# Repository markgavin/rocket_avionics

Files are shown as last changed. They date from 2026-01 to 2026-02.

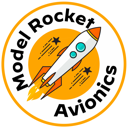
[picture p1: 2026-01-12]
artwork/ModelRocketAvionic128pt.png

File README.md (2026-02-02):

# Rocket Avionics Flight Computer

A complete model rocket avionics system with real-time LoRa telemetry, dual parachute deployment, GPS tracking, and multi-rocket support. Includes flight computer, ground gateway, and desktop/iOS companion apps.

## Overview

The Rocket Avionics system provides comprehensive flight monitoring and recovery capabilities for model and high-power rockets. Real-time telemetry is transmitted via LoRa radio to a ground station, with GPS coordinates enabling rocket recovery after landing.

### Key Features

- **Multi-rocket support** - Track up to 16 rockets simultaneously (IDs 0-15)
- **10 Hz telemetry** via LoRa radio (915 MHz)
- **GPS tracking** with position saved for offline recovery
- **Dual parachute deployment** - Drogue at apogee, main at configurable altitude
- **9-DoF IMU** - Accelerometer, gyroscope, and magnetometer
- **Barometric altitude** using BMP390 precision sensor
- **WiFi connectivity** - Connect apps directly to gateway over WiFi
- **OTA updates** - Update Heltec gateway firmware over WiFi
- **mDNS discovery** - Find gateway at `RocketGateway.local`
- **Cross-platform apps** for macOS, Windows, and iOS
- **Rocket recovery navigation** - iOS app guides you to landed rocket

## System Components

### 1a. Flight Computer - RP2040 (`/firmware_flight/`)
RP2040-based flight computer with Feather ecosystem.

- **Feather RP2040 + RFM95** LoRa radio (915 MHz)
- **BMP390** barometric altitude sensor
- **LSM6DSOX + LIS3MDL** 9-DoF IMU
- **GPS module** for position tracking
- **OLED display** with button navigation
- **Dual pyro channels** with continuity detection
- **~$125 total cost**

### 1b. Flight Computer - Heltec (Lower Cost) (`/firmware_flight_heltec/`)
ESP32-S3 based flight computer with built-in GPS and display.

- **Heltec Wireless Tracker** (ESP32-S3 + SX1262 + GPS + Display)
- **BMP390** barometric altitude (external I2C)
- **LSM6DSOX + LIS3MDL** 9-DoF IMU (external I2C)
- **Built-in GPS** and TFT display
- **Dual pyro channels** with continuity detection
- **~$81 total cost (35% savings)**

### 2. Ground Gateway - Heltec (Recommended) (`/firmware_gateway_heltec/`)
ESP32-S3 based gateway with built-in WiFi, GPS, and display.

- **Heltec Wireless Tracker** (ESP32-S3 + SX1262 + GPS)
- **WiFi AP/Station mode** - Create hotspot or join existing network
- **mDNS** - Discover at `RocketGateway.local`
- **OTA updates** - Flash new firmware over WiFi
- **Built-in display** - Shows rocket status, GPS, packet count
- **TCP server** on port 5000 for app connections

### 3. Ground Gateway - RP2040 (`/firmware_gateway/`)
Alternative gateway using RP2040 with optional WiFi.

- **Feather RP2040 + RFM95** LoRa radio
- **USB serial** output for desktop connection
- **Optional AirLift** WiFi FeatherWing

### 4. Desktop Application (`/desktop_app/`)
Xojo application for macOS and Windows.

- Real-time altitude/velocity charts
- Multi-rocket tracking with rocket list
- Rename rockets with custom names
- Flight data download from flash storage
- Gateway status and configuration
- Flight history database
- Data export (CSV)

### 5. iOS Application (`/ios_app/`)
Xojo mobile app for iPhone.

- Live telemetry display
- **Rocket recovery navigation** - Compass and distance to landed rocket
- Uses iPhone GPS to guide you to rocket location
- Works offline with cached rocket coordinates
- Multi-rocket support with individual recovery

## Hardware

### Flight Computer (RP2040 - Full Featured)
| Component | Description |
|---|---|
| Adafruit Feather RP2040 + RFM95 | MCU with 915 MHz LoRa radio |
| Adafruit BMP390 | Barometric pressure/altitude |
| Adafruit LSM6DSOX + LIS3MDL | 9-DoF IMU FeatherWing |
| Adafruit FeatherWing OLED 128x64 | Status display with buttons |
| GPS Module | UART GPS for position tracking |

### Flight Computer (Heltec - Lower Cost)
| Component | Description |
|---|---|
| Heltec Wireless Tracker | ESP32-S3 + SX1262 + GPS + Display |
| Adafruit BMP390 | Barometric pressure (I2C) |
| Adafruit LSM6DSOX + LIS3MDL | 9-DoF IMU (I2C) |

### Ground Gateway (Heltec - Recommended)
| Component | Description |
|---|---|
| Heltec Wireless Tracker | ESP32-S3 + SX1262 LoRa + GPS + Display |

### Ground Gateway (RP2040 - Alternative)
| Component | Description |
|---|---|
| Adafruit Feather RP2040 + RFM95 | MCU with 915 MHz LoRa radio |
| Adafruit AirLift FeatherWing | Optional WiFi (ESP32) |

## Quick Start

### Flight Computer
```bash
cd firmware_flight
mkdir -p build && cd build
cmake .. && make -j4
picotool load rocket_avionics_flight.uf2 -f
```

### Heltec Gateway
```bash
cd firmware_gateway_heltec
./increment_build.sh
# Use Arduino IDE or arduino-cli to compile and upload
```

### OTA Update (Heltec Gateway)
```bash
python3 ~/Library/Arduino15/packages/Heltec-esp32/hardware/esp32/3.0.3/tools/espota.py \
  -i RocketGateway.local -p 3232 -f firmware_gateway_heltec.ino.bin
```

### Connect to Gateway
```bash
# Via mDNS hostname
nc RocketGateway.local 5000

# Query gateway info
echo '{"cmd":"gw_info"}' | nc RocketGateway.local 5000
```

## Flight Computer Display

The OLED display has two buttons for navigation:

| Button | Action |
|---|---|
| **A** | Cycle through screens: Live → Sensors → Pyro → Storage → Rocket ID → About |
| **B** | On Rocket ID screen: Change ID (0-15). On other screens: Return to Live |

## Multi-Rocket Support

Each flight computer has a unique rocket ID (0-15):

1. Navigate to **Rocket ID** screen (Button A)
2. Press **Button B** to cycle through IDs
3. ID is saved to flash and persists across reboots
4. All telemetry packets include the rocket ID
5. Gateway and apps track all rockets independently

## Flight States

| State | Description | Trigger |
|---|---|---|
| IDLE | On pad, pre-flight | Power on |
| ARMED | Ready for launch | ARM command |
| BOOST | Motor burning | Altitude >10m or velocity >10m/s |
| COAST | Coasting to apogee | Acceleration drops |
| APOGEE | Peak altitude | Velocity crosses zero (fires drogue) |
| DROGUE | Descending on drogue | Drogue deployed |
| MAIN | Main chute altitude | Below configured altitude (fires main) |
| LANDED | On ground | Stationary for 5 seconds |

## Pyro Channels

| Channel | Purpose | Fire Condition |
|---|---|---|
| Pyro 1 | Drogue parachute | At apogee (velocity = 0) |
| Pyro 2 | Main parachute | Below main deploy altitude |

**Safety:** Arm switch must be closed to enable pyro firing.

## Directory Structure

```
rocket_avionics/
├── firmware_flight/          # Flight computer (RP2040, C)
├── firmware_flight_heltec/   # Flight computer (Heltec, Arduino)
├── firmware_gateway/         # RP2040 gateway (C)
├── firmware_gateway_heltec/  # Heltec gateway (Arduino)
├── desktop_app/              # Desktop app (Xojo)
├── ios_app/                  # iOS app (Xojo)
├── hardware/                 # PCB designs
├── docs/                     # Documentation
└── tools/                    # Utility scripts
```

## Documentation

- `CLAUDE.md` - Project overview and coding conventions
- `firmware_flight/CLAUDE.md` - RP2040 flight computer details
- `firmware_flight_heltec/CLAUDE.md` - Heltec flight computer details
- `firmware_gateway_heltec/CLAUDE.md` - Heltec gateway (OTA, mDNS, GPS)
- `desktop_app/CLAUDE.md` - Desktop application
- `ios_app/CLAUDE.md` - iOS app (recovery, multi-rocket)
- `docs/flight_computer_parts_list.md` - RP2040 flight computer BOM
- `docs/heltec_flight_computer_parts_list.md` - Heltec flight computer BOM
- `docs/gateway_parts_list.md` - Gateway options BOM

## License

Copyright (c) 2025-2026 by Mark Gavin. All Rights Reserved.

Proprietary software - not for distribution.

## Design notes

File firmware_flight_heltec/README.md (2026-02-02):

# Heltec Flight Computer

Rocket flight computer firmware for Heltec Wireless Tracker with external BMP390 and IMU sensors.

## Features

- Real-time telemetry at 10Hz via LoRa
- GPS tracking with built-in module
- 9-DoF IMU (accelerometer, gyroscope, magnetometer)
- Barometric altitude measurement
- Dual parachute deployment (drogue + main)
- View-only TFT display
- ~47% cost savings vs RP2040 version

## Hardware Required

| Component | Description | Est. Price |
|---|---|---|
| Heltec Wireless Tracker | ESP32-S3 + SX1262 + GPS + Display | $27 |
| Adafruit BMP390 | Barometric sensor (STEMMA QT) | $12.50 |
| Adafruit LSM6DSOX + LIS3MDL | 9-DoF IMU FeatherWing | $19.95 |
| LiPo Battery 3.7V | 500-1000mAh | $8 |
| **Total** | | **~$67** |

Plus pyro channel components (~$7).

## Wiring

### I2C Sensors

Solder wires from Heltec edge connector to sensors:

| Heltec GPIO | Connect To |
|---|---|
| GPIO 5 | SDA (BMP390 + IMU) |
| GPIO 6 | SCL (BMP390 + IMU) |
| 3.3V | VIN (sensors) |
| GND | GND (sensors) |

### Pyro Channels

| Heltec GPIO | Connect To |
|---|---|
| GPIO 7 | Pyro 1 MOSFET gate (drogue) |
| GPIO 45 | Pyro 2 MOSFET gate (main) |
| GPIO 2 | Pyro 1 continuity divider |
| GPIO 4 | Pyro 2 continuity divider |
| GPIO 46 | Arm switch (to GND when armed) |

## Arduino IDE Setup

1. **Add Heltec board URL** to File → Preferences → Additional Board Manager URLs:
   ```
   https://github.com/Heltec-Aaron-Lee/WiFi_Kit_series/releases/download/0.0.9/package_heltec_esp32_index.json
   ```

2. **Install board**: Tools → Board → Board Manager → Search "Heltec ESP32" → Install

3. **Install libraries** via Library Manager:
   - RadioLib
   - TinyGPSPlus
   - Adafruit GFX Library
   - Adafruit ST7735 and ST7789 Library

4. **Select board**: Tools → Board → Heltec ESP32 → Heltec Wireless Tracker

5. **Upload speed**: 921600

## Building and Flashing

```bash
# Increment build number
./increment_build.sh

# Compile and upload via Arduino IDE
# Or use arduino-cli:
arduino-cli compile --fqbn "Heltec-esp32:esp32:heltec_wireless_tracker" .
arduino-cli upload --fqbn "Heltec-esp32:esp32:heltec_wireless_tracker" -p /dev/cu.usbserial-* .
```

## Flight Procedure

### Pre-Flight

1. Power on flight computer
2. Verify display shows "IDLE" state
3. Wait for GPS lock (green "FIX" on display)
4. Verify pyro continuity (P1:OK, P2:OK)
5. Close arm switch
6. Verify ARM:YES on display
7. Send ARM command from ground station

### Launch

1. Flight computer automatically detects launch (>2g accel or >10m altitude)
2. Real-time telemetry transmitted to gateway
3. Apogee detected → drogue deployed
4. Main altitude reached → main deployed
5. Landing detected → beacon mode

### Post-Flight

1. Open arm switch first!
2. Download flight data via LoRa
3. Power off

## Display Screens

The display shows (no buttons, view-only):

- **Line 1**: Flight state + Rocket ID
- **Line 2**: Altitude + Velocity
- **Line 3**: Max altitude + Acceleration
- **Line 4**: GPS status
- **Line 5**: Pyro continuity + Arm status
- **Line 6**: TX count + Temperature

## Troubleshooting

**Sensors not found**
- Check solder connections on GPIO 5 and 6
- Verify 3.3V power to sensors
- Run I2C scanner sketch to find addresses

**No GPS fix**
- Go outdoors with clear sky view
- Wait 1-2 minutes for cold start
- Built-in antenna is weak but works outdoors

**LoRa not working**
- Check antenna is connected
- Verify gateway is running
- Check sync word matches (0x14)

## License

Copyright (c) 2025-2026 by Mark Gavin. All Rights Reserved.

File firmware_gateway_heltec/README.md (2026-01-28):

# Heltec Gateway Firmware (ESP32-S3)

## Overview

Ground station gateway firmware for Heltec Wireless Tracker. Bridges LoRa telemetry from flight computer to WiFi TCP clients with built-in GPS for ground station location.

## Hardware

- **Board:** Heltec Wireless Tracker (ESP32-S3 + SX1262 LoRa + GPS)
- **LoRa:** SX1262 915MHz with onboard PCB antenna
- **Display:** Built-in 0.96" TFT (ST7735, 160x80 pixels, color)
- **GPS:** Built-in UC6580 GPS module with ceramic chip antenna
- **WiFi:** Built-in ESP32-S3 WiFi

## Antennas

The Wireless Tracker has **built-in antennas** - no external antennas required:

| Antenna | Type | Notes |
|---|---|---|
| **LoRa** | Onboard spring/wire antenna | Ready to use |
| **GPS** | Ceramic chip antenna on PCB | Needs clear sky view for fix |

For extended LoRa range, you can optionally add an external 915MHz antenna via the U.FL connector (if present on your board version).

## Arduino IDE Setup

### 1. Install Heltec Board Support

Add this URL to **File > Preferences > Additional Board Manager URLs**:
```
https://resource.heltec.cn/download/package_heltec_esp32_index.json
```

Install **Heltec ESP32 Series Dev-boards** from Board Manager.

### 2. Install Required Libraries

Go to **Tools > Manage Libraries** and install:
- **RadioLib** by Jan Gromes
- **TinyGPSPlus** by Mikal Hart
- **Adafruit GFX Library** by Adafruit
- **Adafruit ST7735 and ST7789 Library** by Adafruit

### 3. Select Board and Port

- **Board**: Tools → Board → Heltec Wireless Tracker
- **Port**: Select the USB serial port
- **Upload Speed**: 921600

### 4. Upload Firmware

Open `firmware_gateway_heltec.ino` and click Upload.

**If upload fails**, enter bootloader mode manually:
1. Hold **USER** button
2. Press **RESET** button
3. Release RESET, then release USER
4. Try upload again

## Configuration

### LoRa Settings (must match flight computer)

```cpp
#define LORA_FREQUENCY      915.0       // MHz
#define LORA_BANDWIDTH      125.0       // kHz
#define LORA_SPREAD_FACTOR  7
#define LORA_CODING_RATE    5           // 4/5
#define LORA_SYNC_WORD      0x14        // Private sync word
```

### WiFi Settings

```cpp
// Station mode (connect to existing network)
#define WIFI_STA_SSID       "YourHomeWiFi"
#define WIFI_STA_PASSWORD   "YourPassword"
#define WIFI_STA_TIMEOUT_MS 10000

// AP mode (create hotspot) - fallback
#define WIFI_AP_SSID        "RocketGateway"
#define WIFI_AP_PASSWORD    ""          // Empty = open
#define TCP_PORT            5000
```

## WiFi Fallback Mode

1. **Station mode first:** If `WIFI_STA_SSID` is configured, attempts to connect to existing WiFi
2. **AP fallback:** If station mode fails (or SSID empty), creates "RocketGateway" hotspot
3. Display shows current mode ([STA] or [AP]) and IP address

### Connecting

**Station mode:**
- Check display for assigned IP
- Connect to port 5000 at that IP

**AP mode:**
- Connect to WiFi "RocketGateway"
- Connect to `192.168.4.1:5000`

## Pin Definitions

```cpp
// LoRa SX1262
#define LORA_NSS    8
#define LORA_DIO1   14
#define LORA_RST    12
#define LORA_BUSY   13

// GPS UART
#define GPS_RX      33
#define GPS_TX      34

// TFT Display (ST7735 160x80)
#define TFT_MOSI    42
#define TFT_SCLK    41
#define TFT_CS      38
#define TFT_DC      40
#define TFT_RST     39
#define TFT_BL      21      // Backlight
#define TFT_POWER   3       // VEXT (shared with GPS)
```

## Display Layout

The 160x80 color TFT shows:

```
┌────────────────────────────┐
│ GATEWAY            [AP]    │
├────────────────────────────┤
│ 192.168.4.1          C:1   │
│ LoRa:1234      -45dB       │
│ 38.8970,-77.0360           │
│ {"type":"tel"...           │
│ 12:34:56 UTC               │
└────────────────────────────┘
```

- Row 0: Gateway title + WiFi mode (cyan/orange)
- Row 1: IP address + client count
- Row 2: LoRa packet count + RSSI
- Row 3: GPS coordinates (green when valid)
- Row 4: Last packet preview
- Row 5: UTC time from GPS

## Data Flow

```
Flight Computer → LoRa → Heltec → WiFi TCP → Desktop/iOS App
                                    ↓
                                 Display
```

## Troubleshooting

### Upload fails
- Enter bootloader mode manually (USER + RESET)
- Try lower upload speed (460800)

### No LoRa packets received
- Verify frequency/SF/BW match flight computer
- Check sync word matches (0x14)
- Move closer to transmitter for testing

### WiFi not visible
- Check serial output for errors
- Try resetting the board

### GPS no fix
- Move to area with clear sky view
- Wait 1-2 minutes for cold start fix
- Keep the PCB oriented with clear view up

### Display blank
- VEXT (GPIO3) must be HIGH for display power
- Backlight (GPIO21) must be HIGH

## Hardware Versions

| Version | GPS Power Pin | Notes |
|---|---|---|
| V1.0 | GPIO37 | Original |
| V1.1+ | GPIO3 | Current, firmware configured for this |

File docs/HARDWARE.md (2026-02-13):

# Rocket Avionics Hardware Guide

## Overview

The Rocket Avionics system consists of two main hardware assemblies:

1. **Flight Computer** - Mounted in the rocket
2. **Ground Gateway** - Connected to desktop computer via USB

Both use the same base board (Adafruit Feather RP2040 with RFM95 LoRa) for simplified development and interchangeable parts.

---

## Flight Computer Bill of Materials

| Component | Product ID | Quantity | Purpose |
|---|---|---|---|
| Feather RP2040 + RFM95 LoRa 915MHz | 5714 | 1 | Main MCU + LoRa radio |
| BMP390 Barometric Sensor | 4816 | 1 | Altitude measurement (primary) |
| BMP581 Barometric Sensor | 5857 | 1 | Altitude measurement (secondary, higher accuracy) |
| LSM6DSOX + LIS3MDL 9-DoF IMU FeatherWing | 4565 | 1 | Accelerometer, gyroscope, magnetometer |
| Ultimate GPS Breakout (MTK3333) | 5440 | 1 | Position tracking (GPS+GLONASS) |
| FeatherWing OLED 128x64 | 4650 | 1 | Status display |
| Quad Side-By-Side FeatherWing Kit | 4254 | 1 | Mounting all boards |
| LiPo Battery 3.7V 500mAh+ | varies | 1 | Power |

### Sensors

The flight computer supports two barometric pressure sensors and two IMU variants:

**Barometers** (either or both may be installed):
- **BMP390** (I2C 0x77/0x76) -- Requires host-side compensation using 14 NVM calibration coefficients. Accuracy +/-3 Pa.
- **BMP581** (I2C 0x47/0x46) -- Pre-compensated output, no calibration needed. Accuracy +/-0.4 Pa. Chip may report ID 0x50 (BMP580 variant) or 0x51 (BMP581).

**IMUs** (one installed):
- **LSM6DSOX + LIS3MDL** -- 6-axis accel/gyro + 3-axis mag. +/-8g accel, +/-1000 dps gyro.
- **ICM-20649** -- 6-axis accel/gyro. +/-30g accel, +/-4000 dps gyro. Higher range for high-G flights.

The barometer and IMU data are fused using a complementary filter to produce altitude and velocity estimates. See [SENSORS.md](SENSORS.md) for details on the sensor fusion algorithm.

---

## Ground Gateway Bill of Materials

| Component | Product ID | Quantity | Purpose |
|---|---|---|---|
| Feather RP2040 + RFM95 LoRa 915MHz | 5714 | 1 | Gateway MCU + LoRa radio |
| BMP390 Barometric Sensor | 4816 | 1 | Ground pressure reference |
| USB-C Cable | - | 1 | Connection to computer |

The gateway BMP390 provides ground-level pressure readings, enabling differential altitude calculation (height of flight computer above gateway) which is more accurate than absolute altitude from a single sensor.

---

## Pin Assignments

### Feather RP2040 + RFM95 LoRa

The RFM95 LoRa radio is built into the Feather and uses dedicated pins.

#### LoRa Radio (SPI0)

| Function | GPIO | Notes |
|---|---|---|
| SPI SCK | GP18 | SPI0 Clock |
| SPI MOSI | GP19 | SPI0 TX |
| SPI MISO | GP20 | SPI0 RX |
| LoRa CS | GP7 | Chip Select |
| LoRa Reset | GP11 | Radio Reset |
| LoRa DIO0 | GP6 | Interrupt |

#### I2C Bus (STEMMA QT)

| Function | GPIO | Notes |
|---|---|---|
| I2C SDA | GP2 | I2C1 Data |
| I2C SCL | GP3 | I2C1 Clock |

I2C Devices:
- BMP390 Barometer: 0x77 (or 0x76)
- BMP581 Barometer: 0x47 (or 0x46)
- LSM6DSOX Accel/Gyro: 0x6A (or 0x6B)
- LIS3MDL Magnetometer: 0x1C (or 0x1E)
- ICM-20649 Accel/Gyro: 0x68 (or 0x69)
- SSD1306 OLED: 0x3C

#### GPS Module (UART0) - Flight Computer Only

| Function | GPIO | Notes |
|---|---|---|
| UART0 TX | GP0 | To GPS RX |
| UART0 RX | GP1 | From GPS TX |

GPS Configuration:
- Module: Adafruit Ultimate GPS Breakout (PID 5440, MTK3333)
- Baud Rate: 9600
- Protocol: NMEA 0183
- Sentences: GGA, RMC (parser handles both `$GP` and `$GN` prefixes)
- Update Rate: 1 Hz (configurable up to 10 Hz)
- See [GPS.md](GPS.md) for wiring diagram and full details

#### SD Card (Adalogger FeatherWing)

| Function | GPIO | Notes |
|---|---|---|
| SD CS | GP10 | Chip Select |
| SD SCK | GP18 | Shared with LoRa |
| SD MOSI | GP19 | Shared with LoRa |
| SD MISO | GP20 | Shared with LoRa |

**Note:** SD card shares SPI0 with LoRa radio. Only one device can be active at a time - use CS pins to select.

#### OLED FeatherWing Buttons

| Button | GPIO | Function |
|---|---|---|
| A (Left) | GP9 | Cycle display modes |
| B (Middle) | GP8 | Arm/Disarm toggle |
| C (Right) | GP5 | Reserved |

Buttons are active LOW with internal pull-ups.

#### Status LED

| Function | GPIO | Notes |
|---|---|---|
| NeoPixel | GP16 | Built-in WS2812 |

#### Future Pyro Channels

| Function | GPIO | Notes |
|---|---|---|
| Pyro 1 | GP24 | Drogue (reserved) |
| Pyro 2 | GP25 | Main (reserved) |
| Pyro 1 Cont | GP26/A0 | Continuity ADC |
| Pyro 2 Cont | GP27/A1 | Continuity ADC |

---

## Assembly Instructions

### Flight Computer Assembly

1. **Install Headers on FeatherWing Boards**
   - Solder female headers to OLED FeatherWing
   - Solder female headers to Adalogger FeatherWing
   - Solder male headers to Quad Side-By-Side kit plates

2. **Assemble Quad FeatherWing**
   - Connect the four plates using standoffs
   - Install the Feather RP2040 + RFM95 in one slot
   - Install OLED FeatherWing in adjacent slot
   - Install Adalogger FeatherWing in another slot
   - Fourth slot available for future expansion (IMU, GPS)

3. **Connect BMP390 Sensor**
   - Use STEMMA QT cable from Feather to BMP390
   - BMP390 can be mounted externally for better pressure readings

4. **Connect Battery**
   - Use JST connector on Feather for LiPo battery
   - Battery should be 500mAh or larger for adequate flight time

### Ground Gateway Assembly

1. Simply connect the Feather RP2040 + RFM95 to computer via USB-C
2. No additional components required for basic operation
3. Optional: Add antenna extension for better range

---

## LoRa Antenna

Both flight computer and ground gateway use 915 MHz antennas.

### Antenna Options

1. **Wire Antenna** (included with Feather)
   - 1/4 wave: 82mm length
   - Simple, lightweight, included

2. **External Antenna**
   - SMA or u.FL connector (may require modification)
   - Better range and pattern
   - Recommended for ground station

### Antenna Placement

- **Flight Computer**: Mount antenna vertically if possible
- **Ground Station**: Use external antenna on tripod for best reception

---

## Power Requirements

### Flight Computer

| Component | Current (typical) | Current (peak) |
|---|---|---|
| RP2040 | 25 mA | 100 mA |
| RFM95 LoRa TX | - | 120 mA |
| RFM95 LoRa RX | 12 mA | - |
| BMP390 | 0.7 mA | 3.4 mA |
| BMP581 | 0.5 mA | 2.5 mA |
| LSM6DSOX + LIS3MDL | 1.5 mA | 3.0 mA |
| OLED Display | 10 mA | 20 mA |
| GPS | 25 mA | 50 mA |
| **Total** | ~75 mA | ~300 mA |

With a 500 mAh battery, expect 6-8 hours of operation in idle mode, or several hours of active flight operations.

### Ground Gateway

Powered via USB from computer - no battery required.

---

## I2C Bus Scan

### Flight Computer

Expected devices on I2C bus (full sensor configuration):

```
   0  1  2  3  4  5  6  7  8  9  A  B  C  D  E  F
00:          -- -- -- -- -- -- -- -- -- -- -- -- --
10: -- -- -- -- -- -- -- -- -- -- -- -- 1C -- -- --  <- LIS3MDL Mag
20: -- -- -- -- -- -- -- -- -- -- -- -- -- -- -- --
30: -- -- -- -- -- -- -- -- -- -- -- -- 3C -- -- --  <- OLED
40: -- -- -- -- -- -- -- 47 -- -- -- -- -- -- -- --  <- BMP581
50: -- -- -- -- -- -- -- -- -- -- -- -- -- -- -- --
60: -- -- -- -- -- -- -- -- -- -- 6A -- -- -- -- --  <- LSM6DSOX
70: -- -- -- -- -- -- -- 77 -- -- -- -- -- -- -- --  <- BMP390
```

Note: Not all devices may be present. The firmware auto-detects available sensors at startup and uses whatever is installed.

### Ground Gateway

Expected devices on I2C bus:

```
   0  1  2  3  4  5  6  7  8  9  A  B  C  D  E  F
00:          -- -- -- -- -- -- -- -- -- -- -- -- --
10: -- -- -- -- -- -- -- -- -- -- -- -- -- -- -- --
20: -- -- -- -- -- -- -- -- -- -- -- -- -- -- -- --
30: -- -- -- -- -- -- -- -- -- -- -- -- -- -- -- --
40: -- -- -- -- -- -- -- -- -- -- -- -- -- -- -- --
50: -- -- -- -- -- -- -- -- -- -- -- -- -- -- -- --
60: -- -- -- -- -- -- -- -- -- -- -- -- -- -- -- --
70: -- -- -- -- -- -- -- 77 -- -- -- -- -- -- -- --  <- BMP390
```

---

## Wiring Diagram

### Flight Computer

```
                    ┌──────────────────────────────┐
                    │      Quad FeatherWing        │
  ┌─────────────────┼──────────────────────────────┼──────────┐
  │                 │                              │          │
  │  ┌──────────┐   │  ┌──────────┐  ┌──────────┐  │          │
  │  │ Feather  │   │  │   OLED   │  │  9-DoF   │  │          │
  │  │  RP2040  │   │  │FeatherW  │  │   IMU    │  │          │
  │  │ + RFM95  │   │  │          │  │FeatherW  │  │          │
  │  │          │   │  │[Display] │  │ LSM6DSOX │  │          │
  │  │  [LoRa]  │   │  │  A  B    │  │ LIS3MDL  │  │          │
  │  └────┬─────┘   │  └──────────┘  └──────────┘  │          │
  │       │         │                              │          │
  │       │ STEMMA QT (I2C daisy chain)            │          │
  │       │         │                              │          │
  │  ┌────┴─────┐   │  ┌──────────┐  ┌──────────┐  │          │
  │  │  BMP390  │   │  │  BMP581  │  │   GPS    │──┼─ UART1  │
  │  │ Baromet  │   │  │ Baromet  │  │  Module  │  │  GP4/5  │
  │  │  0x77    │   │  │  0x47    │  │          │  │          │
  │  └──────────┘   │  └──────────┘  └──────────┘  │          │
  └─────────────────┴──────────────────────────────┴──────────┘

  All I2C sensors connect via STEMMA QT daisy-chain on GP2 (SDA) / GP3 (SCL)
```

### Ground Gateway

```
  ┌─────────────────┐
  │ Feather RP2040  │
  │    + RFM95      │
  │                 │
  │    [LoRa]       │
  │                 │
  └────────┬────────┘
           │ STEMMA QT
           │
     ┌─────┴─────┐
     │  BMP390   │
     │ Baromet.  │
     │  Sensor   │
     └───────────┘
```

---

## Troubleshooting

### No Display on OLED

1. Check I2C connections (GP2/GP3)
2. Verify OLED address (0x3C or 0x3D)
3. Check that OLED FeatherWing is fully seated

### No Sensor Readings

1. Check STEMMA QT cable connection
2. Verify BMP390 address (0x77 or 0x76)
3. Run I2C scan to detect devices

### No LoRa Communication

1. Verify both units are set to 915 MHz
2. Check antenna connections
3. Ensure ground gateway is powered
4. Check for LoRa CS pin conflicts

### SD Card Not Working

1. Ensure SD card is FAT32 formatted
2. Check SD card is fully inserted
3. Verify CS pin (GP10) is correct
4. Note: Cannot use SD and LoRa simultaneously

### Altitude Reading Stuck or Wrong

1. Check BMP390 I2C connection via STEMMA QT
2. Verify BMP390 address (0x77 or 0x76)
3. BMP390 uses forced mode - readings update on each sample
4. At sea level, expect ~101,000 Pa pressure
5. If readings are ~85,000 Pa, sensor may not be initializing correctly

### GPS Not Getting Fix

1. GPS requires clear sky view - won't work indoors
2. Wait 30-60 seconds for initial fix (cold start); install CR1220 battery for warm starts
3. Check UART connections (GP0 TX to GPS RX, GP1 RX from GPS TX)
4. Verify GPS module baud rate is 9600
5. Verify GPS module power (3.3V from Feather 3V3 pin)
6. Check for valid NMEA sentences (`$GPGGA`/`$GNGGA`, `$GPRMC`/`$GNRMC`)
7. For rocket airframes: connect an external active antenna via uFL connector

### Gateway Ground Pressure Not Working

1. Ensure BMP390 is connected to gateway via STEMMA QT
2. Check I2C address 0x77
3. Gateway firmware must be rebuilt with BMP390 support
4. Ground pressure enables differential altitude calculation

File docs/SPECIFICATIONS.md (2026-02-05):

# System Specifications

## Flight Computer

| Parameter | Value |
|---|---|
| MCU | RP2040 (Dual Cortex-M0+, 133 MHz) |
| Board | Adafruit Feather RP2040 with RFM95 LoRa (PID 5714) |
| Flash | 8 MB (QSPI) |
| RAM | 264 KB |
| Main Loop Rate | 1 kHz (1 ms period) |
| Supply Voltage | 3.3V (USB or LiPo via onboard regulator) |

## Sensor Specifications

### BMP390 Barometer (Primary)

| Parameter | Value |
|---|---|
| I2C Address | 0x77 |
| Pressure Range | 300-1250 hPa |
| Pressure Accuracy | +/- 0.5 hPa |
| Pressure Resolution | 0.016 Pa (24-bit) |
| Temperature Range | -40 to +85 C |
| Temperature Accuracy | +/- 0.5 C |
| Sample Rate | 100 Hz (configured: 50 Hz ODR, oversampled to 100 Hz read) |
| Oversampling | Pressure 8x, Temperature 2x |
| IIR Filter | Coefficient 3 |
| Measured Noise | ~0.05m altitude std (at ground level) |

### BMP581 Barometer (Secondary)

| Parameter | Value |
|---|---|
| I2C Address | 0x47 (default) or 0x46 (alt) |
| Chip ID | 0x50 (BMP580 variant) |
| Pressure Range | 300-1250 hPa |
| Output Format | Pre-compensated (P/64 Pa, T/65536 C) |
| Measured Offset vs BMP390 | +8 Pa pressure, -0.33 C temperature |
| Measured Drift | None detected over 2+ minutes |

### ICM-20649 IMU (Primary)

| Parameter | Value |
|---|---|
| I2C Address | 0x68 (default) or 0x69 (alt) |
| WHO_AM_I | 0xE1 |
| Accel Range | +/- 4g, 8g, 16g, 30g (configured: 8g) |
| Accel Sensitivity | 4096 LSB/g at 8g |
| Accel DLPF | ~50 Hz 3dB bandwidth |
| Accel Sample Rate | 1.125 kHz native, read at 100 Hz |
| Gyro Range | +/- 500, 1000, 2000, 4000 dps (configured: 1000 dps) |
| Gyro Sensitivity | 32.8 LSB/dps at 1000 dps |
| Gyro DLPF | ~51 Hz 3dB bandwidth |
| Gyro Sample Rate | 1.1 kHz native, read at 100 Hz |
| Advantage | 30g max range for high-G flights |

### LSM6DSOX IMU (Fallback)

| Parameter | Value |
|---|---|
| I2C Address | 0x6A |
| WHO_AM_I | 0x6C |
| Accel Range | +/- 2g, 4g, 8g, 16g (configured: 8g) |
| Accel Sensitivity | 0.244 mg/LSB at 8g |
| Accel ODR | 416 Hz |
| Gyro Range | +/- 125, 250, 500, 1000, 2000 dps (configured: 1000 dps) |
| Gyro Sensitivity | 35 mdps/LSB at 1000 dps |
| Gyro ODR | 416 Hz |
| Advantage | Higher precision at lower ranges |

### LIS3MDL Magnetometer

| Parameter | Value |
|---|---|
| I2C Address | 0x1E (default) or 0x1C (alt) |
| WHO_AM_I | 0x3D |
| Range | +/- 4, 8, 12, 16 gauss (configured: 4 gauss) |
| Sensitivity | 6842 LSB/gauss at 4 gauss |
| ODR | 80 Hz (ultra-high performance mode) |
| Performance Mode | Ultra-high (XY + Z axes) |

### PA1616D GPS

| Parameter | Value |
|---|---|
| Interface | UART0, 9600 baud |
| Update Rate | 1 Hz |
| Channels | 22 tracking, 66 searching |
| Sensitivity | -165 dBm tracking |
| Position Accuracy | 3.0m CEP |
| TTFF (Cold) | ~30 seconds |
| TTFF (Hot) | ~1 second |

## Communication

### LoRa Radio (RFM95W)

| Parameter | Value |
|---|---|
| Frequency | 915 MHz (ISM band, North America) |
| Spreading Factor | SF7 |
| Bandwidth | 125 kHz |
| Coding Rate | 4/5 |
| TX Power | 20 dBm (100 mW) |
| Sync Word | 0x14 |
| Preamble | 8 symbols |
| Data Rate | ~5.5 kbps (SF7, 125 kHz) |
| Range | ~1 km line of sight (typical) |
| SPI Bus | SPI1 at 1 MHz |

### Telemetry Packet

| Parameter | Value |
|---|---|
| Packet Size | 55 bytes (LoRaTelemetryPacket) |
| Magic Byte | 0xAF |
| CRC | CRC-8 (polynomial 0x31, init 0xFF) |
| Max Payload | ~255 bytes (LoRa limit) |

## Timing

| Parameter | Value | Rate |
|---|---|---|
| Main Loop | 1 ms | 1 kHz |
| Sensor Sampling | 10 ms | 100 Hz |
| IMU Sampling | 10 ms | 100 Hz |
| Telemetry TX (flight) | 100 ms | 10 Hz |
| Telemetry TX (idle) | 2000 ms | 0.5 Hz |
| Telemetry TX (armed) | 500 ms | 2 Hz |
| Display Update | 200 ms | 5 Hz |
| GPS Update | 1000 ms | 1 Hz |
| Flash Logging | 100 ms | 10 Hz |
| LoRa Timeout | 5000 ms | - |
| Orientation Mode Timeout | 30000 ms | - |

## Flash Storage

| Parameter | Value |
|---|---|
| Total Flash | 8 MB |
| Storage Reserved | 512 KB |
| Flight Slots | 7 |
| Slot Size | 64 KB |
| Sample Size | 52 bytes |
| Max Samples/Flight | 1,200 |
| Max Recording Time | 120 seconds |
| Header Size | 80 bytes |
| Index Magic | 0x58444E49 ("INDX") |
| Flight Magic | 0x54484746 ("FGHT") |

## Display

| Parameter | Value |
|---|---|
| Type | SSD1306 OLED |
| Resolution | 128 x 64 pixels |
| Interface | I2C at 0x3C |
| Update Rate | 5 Hz |
| Screens | 12 modes (Live, Device Info, Flight Stats, LoRa Status, Sensors, GPS, IMU, Spin, Compass, Rates, Rocket ID, About) |

## Buttons

| Button | GPIO | Short Press | Location |
|---|---|---|---|
| A | GP9 | Previous display mode | Left |
| B | GP6 | Home / Edit Rocket ID | Middle |
| C | GP5 | Next display mode | Right |

| Parameter | Value |
|---|---|
| Debounce | 50 ms |
| Long Press | 1000 ms |
| Pull-up | Internal (active low) |

## LED Patterns (NeoPixel)

| State | Color | Period |
|---|---|---|
| IDLE | Green | 1000 ms (1 Hz) |
| ARMED | Yellow | 500 ms (2 Hz) |
| BOOST | Red | 100 ms (10 Hz) |
| DESCENT | Blue | 250 ms (4 Hz) |
| LANDED | White | 2000 ms (0.5 Hz) |

## Sensor Fusion

| Parameter | Value |
|---|---|
| Filter Type | Complementary (2nd order) |
| Crossover Frequency | ~0.5 Hz |
| Altitude Gain (Ka) | 6.0 |
| Velocity Gain (Kv) | 10.0 |
| Bias Learning Rate (Kb) | 1.0 |
| Max Integration dt | 50 ms (clamp) |
| Altitude Smoothing Alpha | 0.1 (~2 Hz cutoff at 100 Hz) |
| Velocity Smoothing Alpha | 0.15 (baro-only fallback) |
| Vertical Axis | Z (accelZ - 1g) |

## I2C Bus

| Parameter | Value |
|---|---|
| Port | I2C1 |
| SDA | GP2 |
| SCL | GP3 |
| Speed | 400 kHz |
| Pull-ups | Internal GPIO pull-ups |

### I2C Device Map

| Address | Device | Function |
|---|---|---|
| 0x3C | SSD1306 | OLED display |
| 0x47 | BMP581 | Barometer (secondary) |
| 0x68 | ICM-20649 | Accel/gyro (primary IMU) |
| 0x6A | LSM6DSOX | Accel/gyro (fallback IMU) |
| 0x77 | BMP390 | Barometer (primary) |
| 0x1E | LIS3MDL | Magnetometer |

## Pyro Channels (Future)

| Channel | Fire GPIO | Continuity GPIO | Purpose |
|---|---|---|---|
| Pyro 1 | GP24 | GP26 (ADC) | Drogue deployment |
| Pyro 2 | GP25 | GP27 (ADC) | Main deployment |

## Multi-Rocket Support

| Parameter | Value |
|---|---|
| Max Rockets | 16 (IDs 0-15) |
| Broadcast ID | 0xFF |
| ID Storage | Flash (persists across reboots) |
| Name Storage | Flash (null-terminated, configurable via LoRa) |

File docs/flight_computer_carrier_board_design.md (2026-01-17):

# Rocket Flight Computer Carrier Board - Design Document

**Author:** Mark Gavin
**Created:** 2026-01-16
**Modified:** 2026-01-17
**Version:** 2.1

## Overview

This document describes the design of a custom carrier board for the Rocket Avionics Flight Computer. The carrier board hosts an Adafruit Feather RP2040 with RFM95 LoRa Radio (Product ID: 5714) via socket headers, along with sensors, pyro deployment channels, and supporting circuitry.

### Design Goals

- Use Feather RP2040 RFM95 as main module (reduces complexity)
- Socket-mount Feather for ease of development and debugging
- All sensors SMD-mounted for vibration resistance
- **Dual SPI buses** for optimal performance and isolation
- Dual pyro channels with continuity detection
- Fits in 54mm (2.1") rocket airframe
- Single 1S LiPo power (uses Feather's onboard charger)

### Target Dimensions

- Board size: ~50mm x 60mm
- Mounting: 4x M2.5 holes for tube rails

---

## Design Decisions

### Why Dual SPI Buses?

| Consideration | Single Bus | Dual Bus |
|---|---|---|
| Speed switching | Required (1-5 MHz) | Not needed |
| LoRa TX blocking | Blocks sensor reads | Sensors independent |
| Complexity | Simpler wiring | Slightly more pins |
| Reliability | Bus contention possible | Full isolation |

**Decision:** Use two SPI buses to isolate high-rate flight sensors from LoRa radio operations.

### Bus Assignment Rationale

| Bus | Devices | Speed | Why |
|-----|---|---|-----|
| **SPI1** | LoRa + BMP390 | 1 MHz | Low-rate devices; barometer data changes slowly |
| **SPI0** | ICM-42688 + ADXL375 | 5 MHz | High-rate flight sensors need fast, uninterrupted reads |

**Benefits:**
- LoRa transmissions don't block critical sensor reads
- IMU and high-G accel can sample at 1000+ Hz without interruption
- No speed switching overhead
- BMP390 doesn't need high speed (pressure changes slowly)

### SPI Device Compatibility

| Device | Max SPI Speed | SPI Mode | Bus Assignment |
|---|---|---|---|
| RFM95 LoRa | 10 MHz | Mode 0 | SPI1 (1 MHz) |
| BMP390 | 10 MHz | Mode 0 | SPI1 (1 MHz) |
| ICM-42688-P | 24 MHz | Mode 0/3 | SPI0 (5 MHz) |
| ADXL375 | 5 MHz | Mode 0/3 | SPI0 (5 MHz) |

All devices support **SPI Mode 0 (CPOL=0, CPHA=0)** - no conflicts.

---

## Feather RP2040 RFM95 Pin Allocation

### Pins Used Internally by Feather (DO NOT USE)

| GPIO | Function | Notes |
|---|---|---|
| GP8 | SPI1 MISO | LoRa radio + BMP390 |
| GP14 | SPI1 SCK | LoRa radio + BMP390 |
| GP15 | SPI1 MOSI | LoRa radio + BMP390 |
| GP16 | RFM95 CS | LoRa chip select |
| GP17 | RFM95 RST | LoRa reset |
| GP18 | RFM95 DIO5 | LoRa (internal) |
| GP19 | RFM95 DIO3 | LoRa (internal) |
| GP20 | RFM95 DIO4 | LoRa (internal) |
| GP21 | RFM95 DIO0 | LoRa RX done interrupt |
| GP22 | RFM95 DIO1 | LoRa (optional) |
| GP23 | RFM95 DIO2 | LoRa (internal) |

### Pins Available for Carrier Board

| GPIO | Feather Label | Carrier Function | Notes |
|---|---|---|---|
| GP0 | TX | GPS RX | UART0 TX to GPS module RX |
| GP1 | RX | GPS TX | UART0 RX from GPS module TX |
| GP2 | SDA | SPI0 SCK | High-rate sensor bus clock |
| GP3 | SCL | SPI0 MOSI | High-rate sensor bus data out |
| GP4 | D4 | NeoPixel | Status LED (onboard) |
| GP5 | D5 | CS_BMP390 | SPI1 chip select |
| GP6 | D6 | CS_ICM42688 | SPI0 chip select |
| GP7 | BOOT | SPI0 MISO | High-rate sensor bus data in |
| GP8 | MISO | SPI1 MISO | LoRa + BMP390 bus |
| GP9 | D9 | CS_ADXL375 | SPI0 chip select |
| GP10 | D10 | Arm Switch | Input, active LOW |
| GP11 | D11 | Buzzer | PWM output for piezo |
| GP12 | D12 | *Available* | Future use |
| GP13 | D13 | *Available* | Future use |
| GP14 | SCK | SPI1 SCK | LoRa + BMP390 bus |
| GP15 | MOSI | SPI1 MOSI | LoRa + BMP390 bus |
| GP24 | D24 | Pyro 1 Fire | Drogue deployment MOSFET gate |
| GP25 | D25 | Pyro 2 Fire | Main deployment MOSFET gate |
| GP26 | A0 | Pyro 1 Continuity | ADC - e-match continuity sense |
| GP27 | A1 | Pyro 2 Continuity | ADC - e-match continuity sense |
| GP28 | A2 | Battery Voltage | ADC - voltage divider input |
| GP29 | A3 | Pyro 3 Continuity | ADC (optional) |

---

## Pin Summary Table

| GPIO | Function | Direction | Type | Notes |
|---|---|---|---|---|
| GP0 | GPS TX | Output | UART0 | To GPS RX |
| GP1 | GPS RX | Input | UART0 | From GPS TX |
| GP2 | SPI0 SCK | Output | SPI | High-rate sensors |
| GP3 | SPI0 MOSI | Output | SPI | High-rate sensors |
| GP4 | NeoPixel | Output | Digital | Status LED |
| GP5 | CS_BMP390 | Output | Digital | SPI1 chip select |
| GP6 | CS_ICM42688 | Output | Digital | SPI0 chip select |
| GP7 | SPI0 MISO | Input | SPI | High-rate sensors |
| GP8 | SPI1 MISO | Input | SPI | LoRa + BMP390 |
| GP9 | CS_ADXL375 | Output | Digital | SPI0 chip select |
| GP10 | Arm Switch | Input | Digital | Pull-up, active LOW |
| GP11 | Buzzer | Output | PWM | Piezo buzzer |
| GP14 | SPI1 SCK | Output | SPI | LoRa + BMP390 |
| GP15 | SPI1 MOSI | Output | SPI | LoRa + BMP390 |
| GP16 | CS_LoRa | Output | Digital | LoRa chip select |
| GP24 | Pyro 1 Fire | Output | Digital | Drogue MOSFET |
| GP25 | Pyro 2 Fire | Output | Digital | Main MOSFET |
| GP26 | Pyro 1 Cont | Input | ADC | Continuity sense |
| GP27 | Pyro 2 Cont | Input | ADC | Continuity sense |
| GP28 | VBAT Sense | Input | ADC | Battery voltage |
| GP29 | Pyro 3 Cont | Input | ADC | Optional |

---

## Dual SPI Bus Configuration

### Bus Architecture

```
┌─────────────────────────────────────────────────────────────────┐
│                     DUAL SPI ARCHITECTURE                        │
│                                                                 │
│  SPI1 (1 MHz) - Low-Rate Bus                                   │
│  ════════════════════════════                                   │
│    GP14 (SCK)  ────┬──── RFM95 LoRa    (CS: GP16)              │
│    GP15 (MOSI) ────┤                                            │
│    GP8  (MISO) ────┴──── BMP390 Baro   (CS: GP5)               │
│                                                                 │
│                                                                 │
│  SPI0 (5 MHz) - High-Rate Sensor Bus                           │
│  ═══════════════════════════════════                           │
│    GP2 (SCK)  ─────┬──── ICM-42688 IMU  (CS: GP6)              │
│    GP3 (MOSI) ─────┤                                            │
│    GP7 (MISO) ─────┴──── ADXL375 Hi-G   (CS: GP9)              │
│                                                                 │
└─────────────────────────────────────────────────────────────────┘
```

### SPI1 - LoRa + Barometer Bus

| Signal | GPIO | Devices |
|---|---|---|
| SCK | GP14 | RFM95, BMP390 |
| MOSI | GP15 | RFM95, BMP390 |
| MISO | GP8 | RFM95, BMP390 |
| CS_LoRa | GP16 | RFM95 |
| CS_BMP390 | GP5 | BMP390 |

**Speed:** 1 MHz (LoRa nominal speed)
**Mode:** Mode 0 (CPOL=0, CPHA=0)

### SPI0 - High-Rate Sensor Bus

| Signal | GPIO | Devices |
|---|---|---|
| SCK | GP2 | ICM-42688, ADXL375 |
| MOSI | GP3 | ICM-42688, ADXL375 |
| MISO | GP7 | ICM-42688, ADXL375 |
| CS_ICM42688 | GP6 | ICM-42688 |
| CS_ADXL375 | GP9 | ADXL375 |

**Speed:** 5 MHz (limited by ADXL375)
**Mode:** Mode 0 (CPOL=0, CPHA=0)

**Note:** GP7 is the BOOT pin on the Feather, but it functions normally as GPIO after boot. Safe to use for SPI0 MISO.

---

## Sensor SPI Connections

### BMP390 (Barometer) - SPI1

| BMP390 Pin | Connect To | Notes |
|---|---|---|
| VDD | 3.3V | |
| GND | GND | |
| CSB | GP5 | Active LOW |
| SDI | GP15 (MOSI) | SPI1 data in |
| SDO | GP8 (MISO) | SPI1 data out |
| SCK | GP14 | SPI1 clock |

### ICM-42688-P (6-DOF IMU) - SPI0

| ICM-42688 Pin | Connect To | Notes |
|---|---|---|
| VDD | 3.3V | |
| VDDIO | 3.3V | |
| GND | GND | |
| CS | GP6 | Active LOW |
| SCLK | GP2 | SPI0 clock |
| SDI | GP3 (MOSI) | SPI0 data in |
| SDO | GP7 (MISO) | SPI0 data out |
| INT1 | *NC* | Optional interrupt |

### ADXL375 (High-G Accelerometer) - SPI0

| ADXL375 Pin | Connect To | Notes |
|---|---|---|
| VDD | 3.3V | |
| VS | 3.3V | |
| GND | GND | |
| CS | GP9 | Active LOW |
| SCLK | GP2 | SPI0 clock |
| MOSI | GP3 | SPI0 data in |
| MISO | GP7 | SPI0 data out |
| INT1 | *NC* | Optional interrupt |

---

## GPS Module (UART0)

| Signal | Feather Pin | GPS Module Pin |
|---|---|---|
| TX | GP0 | RX |
| RX | GP1 | TX |
| VCC | 3.3V | VCC |
| GND | GND | GND |

**Recommended modules:** Quectel L76K, U-blox MAX-M10S, or Adafruit Ultimate GPS

**UART Configuration:** 9600 baud, 8N1

---

## Pyro Channel Circuit

### Schematic

```
                    ┌─────────────────────────────────────┐
                    │         Pyro Channel Circuit        │
                    │                                     │
  GP24 ────[1k]─────┤ Gate                               │
                    │   ┌─────┐                          │
                    │   │     │ Si2302                   │
            GND ────┤───┤ S   │ N-MOSFET                 │
                    │   │     │                          │
                    │   └──┬──┘                          │
                    │      │ Drain                       │
                    │      │                             │
  E-match (-)  ─────┼──────┘                             │
                    │                                     │
  E-match (+)  ─────┼──────────────── VBATT (3.7-4.2V)  │
                    │                                     │
                    │     Continuity Sensing:            │
                    │                                     │
  GP26 (ADC) ───────┼─────┬─────[10k]──── 3.3V          │
                    │     │                              │
                    │     └─────[10k]──── E-match (-)   │
                    │                                     │
                    └─────────────────────────────────────┘
```

### Pyro Channel Assignments

| Channel | Fire GPIO | Continuity ADC | Purpose |
|---|---|---|---|
| Pyro 1 | GP24 | GP26 (A0) | Drogue deployment |
| Pyro 2 | GP25 | GP27 (A1) | Main deployment |
| Pyro 3 | *N/A* | GP29 (A3) | Optional (continuity only) |

### Continuity ADC Values

| Condition | Voltage at ADC | ADC Reading (12-bit) |
|---|---|---|
| Open circuit (no e-match) | ~1.65V | ~2048 |
| E-match connected (~2 ohm) | ~0.02V | ~25 |
| Short circuit | 0V | 0 |

### Safety Notes

- Pyro outputs are LOW by default (MOSFET off)
- Gate resistor (1k) limits current and provides ESD protection
- Always use arm switch to isolate pyro battery until ready
- Consider adding flyback diode across e-match terminals

---

## Arming Switch Circuit

```
  3.3V ────[10k]────┬──── GP10 (input, active LOW)
                    │
                    └──── Arm Switch ──── GND
```

| Switch State | GP10 Reading | System State |
|---|---|---|
| OPEN | HIGH | SAFE - Pyros disabled |
| CLOSED | LOW | ARMED - Pyros enabled |

---

## Battery Voltage Monitor

```
  VBATT ────[100k]────┬──── GP28 (A2, ADC)
                      │
                      └────[100k]──── GND
```

**Voltage calculation:**
```c
float vbat = adc_reading * 2.0f * 3.3f / 4096.0f;
```

| Battery State | VBATT | ADC Voltage | ADC Reading |
|---|---|---|---|
| Full (4.2V) | 4.2V | 2.1V | ~2606 |
| Nominal (3.7V) | 3.7V | 1.85V | ~2296 |
| Low (3.3V) | 3.3V | 1.65V | ~2048 |
| Critical (3.0V) | 3.0V | 1.5V | ~1862 |

---

## Buzzer Circuit

```
  GP11 ────[100]────┬──── Piezo (+)
                    │
            GND ────┴──── Piezo (-)
```

Use PWM at 2-4kHz for audible tone. Useful for:
- Arming confirmation beeps
- Low battery warning
- Landing locator beacon

---

## Block Diagram

```
┌───────────────────────────────────────────────────────────────────────────┐
│                    CARRIER BOARD v2.1 (Dual SPI)                          │
│                                                                           │
│   ┌─────────────────────────────────────────────────────────────────┐    │
│   │                   FEATHER RP2040 RFM95                          │    │
│   │                   (Socket Mounted)                              │    │
│   │                                                                 │    │
│   │  USB  3V3  GND  GP0  GP1  GP2  GP3  GP4  GP5  GP6  GP7  GP9   │    │
│   │   │    │    │    │    │    │    │    │    │    │    │    │    │    │
│   │   │    │    │    │    │    │    │    │    │    │    │    │    │    │
│   │  GP8(MISO1) GP10 GP11 GP14(SCK1) GP15(MOSI1) GP16(CS_LoRa)   │    │
│   │    │         │    │      │          │           │             │    │
│   └────┼─────────┼────┼──────┼──────────┼───────────┼─────────────┘    │
│        │         │    │      │          │           │                   │
│        │         │    │      │          │           └──► LoRa Radio     │
│        │         │    │      │          │               (onboard)       │
│        │         │    │      │          │                               │
│   ┌────┴─────────┼────┼──────┴──────────┴───────────────────────┐      │
│   │   SPI1 Bus   │    │        (1 MHz - LoRa + Barometer)       │      │
│   │              │    │                                          │      │
│   │         ┌────────────┐                                       │      │
│   │         │   BMP390   │                                       │      │
│   │         │  Barometer │                                       │      │
│   │         │   CS: GP5  │                                       │      │
│   │         └────────────┘                                       │      │
│   └──────────────────────────────────────────────────────────────┘      │
│                  │    │                                                  │
│                  │    │   ARM Switch    Buzzer                          │
│                  │    │      GP10        GP11                           │
│                  │    │                                                  │
│   ┌──────────────┴────┴─────────────────────────────────────────┐      │
│   │              GP2  GP3  GP7                                   │      │
│   │   SPI0 Bus  (SCK)(MOSI)(MISO)   (5 MHz - Flight Sensors)    │      │
│   │                                                              │      │
│   │    ┌────────────┐         ┌────────────┐                    │      │
│   │    │ ICM-42688  │         │  ADXL375   │                    │      │
│   │    │  6-DOF IMU │         │   ±200g    │                    │      │
│   │    │   CS: GP6  │         │   CS: GP9  │                    │      │
│   │    └────────────┘         └────────────┘                    │      │
│   └──────────────────────────────────────────────────────────────┘      │
│                                                                          │
│                                                                          │
│   ┌─────────────┐    ┌─────────────────────┐    ┌─────────────┐        │
│   │  GPS Module │    │    Pyro Channels    │    │   Control   │        │
│   │             │    │                     │    │             │        │
│   │  ┌───────┐  │    │  ┌─────┐  ┌─────┐  │    │  ARM   GP10 │        │
│   │  │Quectel│  │    │  │Pyro1│  │Pyro2│  │    │  BZR   GP11 │        │
│   │  │ L76K  │  │    │  │GP24 │  │GP25 │  │    │  LED   GP4  │        │
│   │  └───┬───┘  │    │  │ADC26│  │ADC27│  │    │  VBAT  GP28 │        │
│   │      │      │    │  └──┬──┘  └──┬──┘  │    └─────────────┘        │
│   │   UART0     │    │     │        │     │                            │
│   │   GP0/GP1   │    │  ┌──┴────────┴──┐  │                            │
│   └─────────────┘    │  │ Screw Terms  │  │                            │
│                      │  │  E-matches   │  │                            │
│                      │  └──────────────┘  │                            │
│                      └─────────────────────┘                            │
│                                                                          │
│   ┌───────────────────────────────────────────────────────────────┐    │
│   │  POWER                                                         │    │
│   │                                                                │    │
│   │  LiPo 1S ──► Feather Charger ──► 3.3V Rail ──► All ICs       │    │
│   │  (JST-PH)    (onboard)                                         │    │
│   │                                                                │    │
│   └───────────────────────────────────────────────────────────────┘    │
│                                                                          │
│   Mounting: 4x M2.5 holes for 54mm (2.1") tube rails                    │
│   Dimensions: ~50mm x 60mm                                               │
└──────────────────────────────────────────────────────────────────────────┘
```

---

## Bill of Materials

### Main Components

| Ref | Part | Description | Package | Qty | Est. Price |
|-----|---|---|---|-----|---|
| U1 | BMP390 | Barometric pressure sensor | LGA-10 | 1 | $5.00 |
| U2 | ICM-42688-P | 6-DOF IMU (accel/gyro) | LGA-14 | 1 | $5.00 |
| U3 | ADXL375 | High-G accelerometer ±200g | LGA-14 | 1 | $15.00 |
| U4 | Quectel L76K | GPS module | Module | 1 | $10.00 |
| Q1, Q2 | Si2302 | N-MOSFET (pyro driver) | SOT-23 | 2 | $0.50 |

### Connectors

| Ref | Part | Description | Package | Qty | Est. Price |
|-----|---|---|---|-----|---|
| J1 | Female headers | 2x 16-pos for Feather | 2.54mm | 1 | $2.00 |
| J2, J3 | Screw terminal | 2-pos (pyro outputs) | 5.08mm | 2 | $1.00 |
| J4 | u.FL | GPS antenna connector | SMD | 1 | $0.50 |
| J5 | JST-PH 2-pin | LiPo battery (optional) | 2mm | 1 | $0.30 |

### Switches and Indicators

| Ref | Part | Description | Package | Qty | Est. Price |
|-----|---|---|---|-----|---|
| SW1 | SPST slide | Arm switch | Through-hole | 1 | $0.50 |
| BZ1 | Piezo buzzer | 12mm passive | Through-hole | 1 | $1.00 |

### Passive Components

| Ref | Value | Description | Package | Qty | Est. Price |
|-----|---|---|---|-----|---|
| R1, R2 | 1k | Pyro gate resistors | 0402 | 2 | $0.05 |
| R3, R4, R5, R6 | 10k | Continuity dividers | 0402 | 4 | $0.10 |
| R7, R8 | 100k | VBAT divider | 0402 | 2 | $0.05 |
| R9 | 10k | Arm switch pull-up | 0402 | 1 | $0.02 |
| R10 | 100 | Buzzer series | 0402 | 1 | $0.02 |
| C1-C8 | 0.1uF | Decoupling caps | 0402 | 8 | $0.15 |
| C9-C12 | 10uF | Bulk caps | 0603 | 4 | $0.20 |

### PCB

| Item | Description | Qty | Est. Price |
|---|---|-----|---|
| PCB | 4-layer, ENIG, 50x60mm | 5 | $15.00 ea |

### Cost Summary

| Category | Cost |
|---|---|
| Carrier board components | ~$42 |
| PCB (each, qty 5) | ~$15 |
| Feather RP2040 RFM95 | $25 |
| **Total per unit** | **~$82** |

---

## PCB Design Notes

### Layer Stackup (4-layer)

1. **Top** - Signal + components
2. **Inner 1** - Ground plane (solid)
3. **Inner 2** - Power (3.3V)
4. **Bottom** - Signal + GPS antenna

### Layout Guidelines

1. **SPI0 routing** - Keep GP2, GP3, GP7 traces short and matched length
2. **SPI1 routing** - GP8, GP14, GP15 route to BMP390 (LoRa already connected)
3. **Chip selects** - Route CS lines away from clocks, add 10k pull-ups to 3.3V
4. **GPS antenna** - Keep clear of noisy signals, place u.FL near board edge
5. **Pyro traces** - Use wider traces (0.5mm+) for current handling
6. **Sensor placement** - Mount IMU and high-G accel near board center (center of rotation)
7. **Decoupling caps** - Place 0.1uF close to each IC power pin

### SPI Signal Integrity

- Keep SPI trace lengths under 50mm
- Use ground plane under SPI traces
- Add series termination resistors (33Ω) if needed for signal integrity
- Ensure CS lines have clean transitions (no ringing)

### GP7 (BOOT) Pin Note

GP7 is the BOOT pin on the Feather RP2040. It has an internal pull-up and is used during boot to enter USB bootloader mode. After boot, it functions as a normal GPIO and is safe to use for SPI0 MISO. The internal pull-up should not affect SPI operation.

### Mechanical

- 4x M2.5 mounting holes at corners
- Keep components away from mounting holes (3mm clearance)
- Consider conformal coating for moisture protection

---

## Firmware Pin Definitions

Update `firmware_flight/include/pins.h`:

```c
//----------------------------------------------
// Carrier Board Pin Assignments (Dual SPI Version)
// Hardware: Custom carrier board v2.1
//----------------------------------------------

//----------------------------------------------
// SPI1 Bus (LoRa + Barometer) - 1 MHz
//----------------------------------------------
#define kPinSpi1Sck         14  // GP14 - SPI1 SCK
#define kPinSpi1Mosi        15  // GP15 - SPI1 TX/MOSI
#define kPinSpi1Miso        8   // GP8 - SPI1 RX/MISO
#define kSpi1Port           spi1
#define kSpi1Baudrate       1000000  // 1 MHz

// SPI1 Chip Selects
#define kPinLoRaCs          16  // GP16 - RFM95 LoRa
#define kPinBMP390Cs        5   // GP5 - Barometer

//----------------------------------------------
// SPI0 Bus (High-Rate Sensors) - 5 MHz
//----------------------------------------------
#define kPinSpi0Sck         2   // GP2 - SPI0 SCK
#define kPinSpi0Mosi        3   // GP3 - SPI0 TX/MOSI
#define kPinSpi0Miso        7   // GP7 - SPI0 RX/MISO (BOOT pin)
#define kSpi0Port           spi0
#define kSpi0Baudrate       5000000  // 5 MHz (limited by ADXL375)

// SPI0 Chip Selects
#define kPinICM42688Cs      6   // GP6 - 6-DOF IMU
#define kPinADXL375Cs       9   // GP9 - High-G accelerometer

//----------------------------------------------
// GPS (UART0)
//----------------------------------------------
#define kPinGpsTx           0   // GP0 - UART0 TX (to GPS RX)
#define kPinGpsRx           1   // GP1 - UART0 RX (from GPS TX)
#define kGpsUartPort        uart0
#define kGpsUartBaudrate    9600

//----------------------------------------------
// Pyro Channels
//----------------------------------------------
#define kPinPyro1Fire       24  // GP24 - Drogue deployment
#define kPinPyro2Fire       25  // GP25 - Main deployment
#define kPinPyro1Cont       26  // GP26/A0 - Drogue continuity ADC
#define kPinPyro2Cont       27  // GP27/A1 - Main continuity ADC
#define kPinPyro3Cont       29  // GP29/A3 - Optional 3rd channel ADC

//----------------------------------------------
// Control Inputs
//----------------------------------------------
#define kPinArmSwitch       10  // GP10 - Arm switch (active LOW)

//----------------------------------------------
// Outputs
//----------------------------------------------
#define kPinBuzzer          11  // GP11 - Piezo buzzer (PWM)
#define kPinNeoPixel        4   // GP4 - Status LED (onboard)

//----------------------------------------------
// Analog Inputs
//----------------------------------------------
#define kPinVbatSense       28  // GP28/A2 - Battery voltage

//----------------------------------------------
// LoRa Radio Configuration
//----------------------------------------------
#define kLoRaFrequency      915000000   // 915 MHz ISM band
#define kLoRaSpreadFactor   7           // SF7 for fastest data rate
#define kLoRaBandwidth      125000      // 125 kHz bandwidth
#define kLoRaCodingRate     5           // 4/5 coding rate
#define kLoRaPreambleLen    8           // Preamble length
#define kLoRaTxPower        20          // 20 dBm (100 mW)
#define kLoRaSyncWord       0x14        // Private sync word

//----------------------------------------------
// Sensor Configuration
//----------------------------------------------
#define kICM42688AccelRange     16      // ±16g
#define kICM42688GyroRange      2000    // ±2000 dps
#define kICM42688SampleRate     1000    // 1 kHz ODR
#define kADXL375Range           200     // ±200g (fixed)
#define kADXL375SampleRate      3200    // Up to 3.2 kHz with SPI

//----------------------------------------------
// Timing
//----------------------------------------------
#define kTelemetryIntervalMs        100     // 10 Hz LoRa telemetry
#define kSensorSampleIntervalMs     1       // 1000 Hz sensor sampling
#define kBaroSampleIntervalMs       20      // 50 Hz barometer sampling
#define kDisplayUpdateIntervalMs    200     // 5 Hz display update
```

---

## SPI Driver Implementation

### Initialization

```c
#include "hardware/spi.h"

void InitSpiBuses(void) {
    //--- SPI1: LoRa + Barometer (1 MHz) ---
    spi_init(kSpi1Port, kSpi1Baudrate);
    gpio_set_function(kPinSpi1Sck, GPIO_FUNC_SPI);
    gpio_set_function(kPinSpi1Mosi, GPIO_FUNC_SPI);
    gpio_set_function(kPinSpi1Miso, GPIO_FUNC_SPI);

    // CS pins for SPI1
    gpio_init(kPinLoRaCs);
    gpio_set_dir(kPinLoRaCs, GPIO_OUT);
    gpio_put(kPinLoRaCs, 1);  // Deselect

    gpio_init(kPinBMP390Cs);
    gpio_set_dir(kPinBMP390Cs, GPIO_OUT);
    gpio_put(kPinBMP390Cs, 1);  // Deselect

    //--- SPI0: High-Rate Sensors (5 MHz) ---
    spi_init(kSpi0Port, kSpi0Baudrate);
    gpio_set_function(kPinSpi0Sck, GPIO_FUNC_SPI);
    gpio_set_function(kPinSpi0Mosi, GPIO_FUNC_SPI);
    gpio_set_function(kPinSpi0Miso, GPIO_FUNC_SPI);

    // CS pins for SPI0
    gpio_init(kPinICM42688Cs);
    gpio_set_dir(kPinICM42688Cs, GPIO_OUT);
    gpio_put(kPinICM42688Cs, 1);  // Deselect

    gpio_init(kPinADXL375Cs);
    gpio_set_dir(kPinADXL375Cs, GPIO_OUT);
    gpio_put(kPinADXL375Cs, 1);  // Deselect
}
```

### Transfer Functions

```c
// SPI1 transfer (LoRa + Barometer)
void Spi1Transfer(uint8_t csPin, uint8_t* txBuf, uint8_t* rxBuf, size_t len) {
    gpio_put(csPin, 0);  // Assert CS
    spi_write_read_blocking(kSpi1Port, txBuf, rxBuf, len);
    gpio_put(csPin, 1);  // Deassert CS
}

// SPI0 transfer (High-rate sensors)
void Spi0Transfer(uint8_t csPin, uint8_t* txBuf, uint8_t* rxBuf, size_t len) {
    gpio_put(csPin, 0);  // Assert CS
    spi_write_read_blocking(kSpi0Port, txBuf, rxBuf, len);
    gpio_put(csPin, 1);  // Deassert CS
}

// Convenience wrappers
void BMP390_SpiTransfer(uint8_t* tx, uint8_t* rx, size_t len) {
    Spi1Transfer(kPinBMP390Cs, tx, rx, len);
}

void ICM42688_SpiTransfer(uint8_t* tx, uint8_t* rx, size_t len) {
    Spi0Transfer(kPinICM42688Cs, tx, rx, len);
}

void ADXL375_SpiTransfer(uint8_t* tx, uint8_t* rx, size_t len) {
    Spi0Transfer(kPinADXL375Cs, tx, rx, len);
}
```

### Main Loop Example

```c
void FlightLoop(void) {
    uint32_t lastSensorRead = 0;
    uint32_t lastBaroRead = 0;
    uint32_t lastTelemetry = 0;

    while (true) {
        uint32_t now = time_us_32() / 1000;  // ms

        // High-rate sensor sampling (1000 Hz) - SPI0
        if (now - lastSensorRead >= kSensorSampleIntervalMs) {
            lastSensorRead = now;
            ICM42688_ReadAccelGyro(&imuData);   // SPI0
            ADXL375_ReadAccel(&highGData);      // SPI0
        }

        // Barometer sampling (50 Hz) - SPI1
        if (now - lastBaroRead >= kBaroSampleIntervalMs) {
            lastBaroRead = now;
            BMP390_ReadPressure(&baroData);     // SPI1
        }

        // LoRa telemetry (10 Hz) - SPI1
        if (now - lastTelemetry >= kTelemetryIntervalMs) {
            lastTelemetry = now;
            LoRa_SendTelemetry(&telemetry);     // SPI1
        }
    }
}
```

---

## References

- [Adafruit Feather RP2040 RFM95 Pinouts](https://learn.adafruit.com/feather-rp2040-rfm95/pinouts)
- [Adafruit Feather RP2040 RFM PCB Files (GitHub)](https://github.com/adafruit/Adafruit-Feather-RP2040-RFM-PCB)
- [BMP390 Datasheet](https://www.bosch-sensortec.com/media/boschsensortec/downloads/datasheets/bst-bmp390-ds002.pdf)
- [ICM-42688-P Datasheet](https://invensense.tdk.com/download-pdf/icm-42688-p-datasheet/)
- [ADXL375 Datasheet](https://www.analog.com/media/en/technical-documentation/data-sheets/ADXL375.PDF)
- [RP2040 Datasheet](https://datasheets.raspberrypi.com/rp2040/rp2040-datasheet.pdf)

---

## Revision History

| Version | Date | Changes |
|---|---|---|
| 1.0 | 2026-01-16 | Initial design document (I2C version) |
| 2.0 | 2026-01-17 | Changed to single SPI bus for all sensors |
| 2.1 | 2026-01-17 | Dual SPI architecture: SPI0 for high-rate sensors, SPI1 for LoRa + barometer |

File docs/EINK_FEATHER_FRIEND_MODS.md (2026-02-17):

# eInk Feather Friend Board Modifications

## Overview

The Adafruit eInk Feather Friend (PID 4446) is designed to plug directly into the Feather header and use the Feather's hardware SPI bus. For the Rocket Avionics flight computer (Feather RP2040 RFM95), this creates two problems:

1. **SPI bus conflict**: The Feather Friend's SPI (SCK/MOSI/MISO) routes through the Feather header to SPI1 (GP14/GP15/GP8), which is shared with the LoRa radio. Both devices cannot share a bus across two cores.
2. **RST tied to Feather Reset**: The display RST is connected to the Feather's reset circuit, not a GPIO pin. The firmware needs GPIO-controlled reset on GP12.

The solution: cut the SPI traces on the Feather Friend and wire them to dedicated bit-banged SPI pins (GP24/GP25), and cut the RST trace to wire to GP12.

---

## Feather Friend Default Pin Mapping

The Feather Friend connects these signals through the Feather header:

| Signal | Feather Pin | RP2040 GPIO | Purpose |
|---|---|---|---|
| SCK | SPI SCK | GP14 | SPI clock (shared with LoRa) |
| MOSI | SPI MOSI | GP15 | SPI data out (shared with LoRa) |
| MISO | SPI MISO | GP8 | SPI data in (shared with LoRa) |
| ECS | D9 | GP9 | eInk chip select |
| DC | D10 | GP10 | Data/Command |
| SRCS | D6 | GP6 | SRAM chip select |
| SDCS | D5 | GP5 | SD card chip select |
| RST | RST | (reset circuit) | Display reset (auto-reset) |
| BUSY | (breakout pad) | (not connected) | Busy signal |

## Firmware Pin Mapping (After Modifications)

| Signal | RP2040 GPIO | Source |
|---|---|---|
| SCK | GP24 | Bodge wire from Feather Friend SCK pad |
| MOSI | GP25 | Bodge wire from Feather Friend MOSI pad |
| ECS | GP9 | Feather header (unchanged) |
| DC | GP10 | Feather header (unchanged) |
| SRCS | GP6 | Feather header (unchanged, held high) |
| SDCS | GP5 | Feather header (unchanged, held high) |
| RST | GP12 | Bodge wire from Feather Friend RST pad |
| BUSY | GP13 | Wire from BUSY breakout pad |

---

 Required trace cuts (3):                                                                                                                                        
  1. SCK — disconnect from Feather SPI header (GP14), rewire to GP24
  2. MOSI — disconnect from Feather SPI header (GP15), rewire to GP25                                                                                             
  3. RST — disconnect from Feather reset circuit, rewire to GP12                

  Optional trace cuts (3):
  4. MISO — unused (display is write-only), prevents interference with LoRa reads
  5. SDCS (D5) — SD card unused, frees GP5 for Button C
  6. SRCS (D6) — SRAM unused, frees GP6 for Button B

  Wires to add (4):
  - SCK pad → GP24, MOSI pad → GP25, RST pad → GP12, BUSY breakout pad → GP13

  The ECS (D9/GP9) and DC (D10/GP10) pins pass through the Feather header unchanged — no cuts needed for those.

## Traces to Cut

Cut these traces on the **back** of the Feather Friend PCB. Use an X-Acto knife or PCB trace cutter. Verify each cut with a multimeter (continuity test between the pad and Feather header pin).

### Cut 1: SCK Trace

**Why:** Disconnect SPI clock from the Feather header (GP14) to prevent bus contention with LoRa radio.

- Locate the trace running from the SCK pad on the 24-pin FPC connector side to the Feather header SCK pin.
- Cut the trace between the pad and the header pin.
- After cutting, wire the SCK pad to **GP24 (D24)** on the Feather.

### Cut 2: MOSI Trace

**Why:** Disconnect SPI data out from the Feather header (GP15) to prevent bus contention with LoRa radio.

- Locate the trace running from the MOSI pad to the Feather header MOSI pin.
- Cut the trace between the pad and the header pin.
- After cutting, wire the MOSI pad to **GP25 (D25)** on the Feather.

### Cut 3: RST Trace

**Why:** Disconnect display reset from the Feather's reset circuit. The firmware needs to control RST via GPIO for the triple-reset init sequence and board auto-detection.

- Locate the trace running from the RST pad to the Feather RST header pin (or auto-reset circuit components).
- Cut the trace.
- After cutting, wire the RST pad to **GP12 (D12)** on the Feather.

---

## Traces to Optionally Cut

These traces are not strictly required to cut because the firmware initializes the corresponding GPIO pins HIGH (deselected), but cutting them is recommended to eliminate any possibility of bus noise.

### Optional Cut 4: MISO Trace

**Why:** The eInk display is write-only (no data read back). MISO is only used by the SRAM chip and SD card, neither of which are used. Cutting prevents any MISO drive from interfering with LoRa SPI reads.

- Locate the MISO trace running to the Feather header MISO pin (GP8).
- Cut the trace.
- No bodge wire needed (MISO is unused).

### Optional Cut 5: SDCS Trace (D5)

**Why:** The SD card slot is not used. Cutting the trace frees GP5 for the OLED FeatherWing Button C.

- Locate the SDCS trace to Feather header D5.
- Cut the trace.

### Optional Cut 6: SRCS Trace (D6)

**Why:** The 32KB SRAM chip is not used (the firmware uses its own framebuffer in RP2040 RAM). Cutting the trace frees GP6 for the OLED FeatherWing Button B.

- Locate the SRCS trace to Feather header D6.
- Cut the trace.

---

## Wires to Add

After cutting traces, add these bodge wires:

| From (Feather Friend) | To (Feather RP2040 RFM95) | Wire |
|---|---|---|
| SCK pad | GP24 (D24) | 30 AWG wire-wrap or Kynar |
| MOSI pad | GP25 (D25) | 30 AWG wire-wrap or Kynar |
| RST pad | GP12 (D12) | 30 AWG wire-wrap or Kynar |
| BUSY breakout pad | GP13 (D13) | 30 AWG wire-wrap or Kynar |

### BUSY Pin Note

The BUSY pin is **not** connected to any Feather header pin by default on the Feather Friend. There is a breakout pad labeled BUSY on the board. Wiring BUSY to GP13 (D13) is **optional**. If wired, the firmware polls BUSY for faster display updates. If not wired, the driver automatically falls back to fixed timing delays (3s full refresh, 500ms partial), which works reliably but is slightly slower. Board auto-detection also adapts: with BUSY wired, the board is detected by BUSY toggling; without BUSY, the firmware assumes Feather Friend after the BUSY probe times out.

---

## Pin Conflict Notes

The eInk Feather Friend's default pins overlap with the OLED FeatherWing buttons:

| GPIO | eInk Feather Friend | OLED FeatherWing |
|---|---|---|
| GP9 | ECS (eInk CS) | Button A |
| GP6 | SRCS (SRAM CS) | Button B |
| GP5 | SDCS (SD CS) | Button C |

**Resolution:** In eInk builds (`DISPLAY_EINK` defined), `InitializeButtons()` is skipped entirely. The OLED FeatherWing buttons are not physically present when using the eInk Feather Friend, and initializing those pins as inputs would break the eInk CS/SRAM/SD chip selects. The pins remain as SPI outputs (HIGH/deselected) set by `InitializeSPI()`.

---

## Verification Checklist

After making modifications:

- [ ] Continuity: SCK pad to GP24 (D24) on Feather
- [ ] Continuity: MOSI pad to GP25 (D25) on Feather
- [ ] Continuity: RST pad to GP12 (D12) on Feather
- [ ] Continuity: BUSY pad to GP13 (D13) on Feather
- [ ] No continuity: SCK pad to Feather header SCK (GP14)
- [ ] No continuity: MOSI pad to Feather header MOSI (GP15)
- [ ] No continuity: RST pad to Feather header RST
- [ ] No continuity: MISO pad to Feather header MISO (GP8) (if cut)
- [ ] Flash firmware and verify display initializes (check USB console for `EPD: Detected: eInk Feather Friend`)

---

## Reference

- [Adafruit eInk Feather Friend (PID 4446)](https://www.adafruit.com/product/4446)
- [Adafruit 2.9" eInk Display Pinouts](https://learn.adafruit.com/adafruit-2-9-eink-display-breakouts-and-featherwings/pinouts)
- [Feather RP2040 RFM95 Pinouts](https://learn.adafruit.com/feather-rp2040-rfm95/pinouts)
- Schematics: `hardware/eInkBreakoutFriend/Adafruit eInk Feather Friend.sch`
- Firmware pin definitions: `firmware_flight/include/pins.h`
- eInk display architecture: `docs/EINK_DISPLAY.md`

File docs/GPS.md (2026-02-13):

# GPS Integration

## Overview

The flight computer uses an Adafruit Ultimate GPS module connected via UART for position tracking, ground speed, heading, and UTC time. GPS data is included in telemetry packets and flash-stored flight recordings.

Source: `firmware_flight/src/gps.c`, `firmware_flight/include/gps.h`

## Supported Modules

Two Adafruit Ultimate GPS modules are supported:

| | FeatherWing (PID 3133) | Breakout (PID 5440) |
|---|---|---|
| Chipset | MT3339 | MTK3333 |
| GNSS | GPS only | GPS + GLONASS |
| Channels | 22 tracking / 66 searching | 33 tracking / 99 searching |
| Sensitivity | -165 dBm | -165 dBm |
| Accuracy | < 3 m | < 3 m |
| Antenna | Built-in patch | Built-in patch + uFL for external |
| Enable Pin | Hardwired always-on | EN pin (active high, internal pull-up) |
| PPS | Available | Available |
| Backup Battery | CR1220 footprint | CR1220 footprint |
| NMEA Prefix | `$GP` | `$GN` (multi-GNSS) or `$GP` |

**Recommended:** The Breakout (PID 5440) is preferred for rocket flights because:
- GPS + GLONASS provides faster fix acquisition and more satellites
- uFL connector allows an external active antenna for better reception inside a rocket airframe
- CR1220 backup battery enables warm starts (faster fix after power cycle)

The NMEA parser handles both `$GP` and `$GN` prefixes — it matches sentence types at offset +3 (e.g., `GGA`, `RMC`), so the talker ID is ignored.

## Hardware Interface

| Parameter | Value |
|---|---|
| Interface | UART0 at 9600 baud, 8N1 |
| TX Pin | GP0 (UART0 TX → GPS RX) |
| RX Pin | GP1 (UART0 RX → GPS TX) |
| Logic Level | 3.3V (5V-safe input) |
| Power | 3.0–5.5V, ~29 mA tracking / 34 mA acquisition |
| Update Rate | 1 Hz (configurable up to 10 Hz) |

## Wiring: GPS Breakout (PID 5440) to Feather RP2040 RFM95

```
Adafruit Ultimate GPS              Feather RP2040
Breakout (PID 5440)                + RFM95 LoRa
┌──────────────────┐               ┌──────────────────┐
│                  │               │                  │
│  VIN ────────────────────────────── 3V3              │
│                  │               │                  │
│  GND ────────────────────────────── GND              │
│                  │               │                  │
│  TX  ────────────────────────────── GP1 (UART0 RX)   │
│                  │               │                  │
│  RX  ────────────────────────────── GP0 (UART0 TX)   │
│                  │               │                  │
│  EN  ── n/c (internal pull-up)   │                  │
│  FIX ── n/c (LED on breakout)    │                  │
│  PPS ── n/c (no free GPIO)       │                  │
│                  │               │                  │
└──────────────────┘               └──────────────────┘

4 wires: VIN, GND, TX, RX
```

**Notes:**
- **VIN** accepts 3.0–5.5V. Use Feather 3V3 pin (regulated) or USB pin (5V when USB connected).
- **TX/RX crossover:** GPS TX connects to Feather RX (GP1), GPS RX connects to Feather TX (GP0).
- **EN pin:** Leave unconnected — internal pull-up keeps GPS always enabled. On a carrier board with a free GPIO, EN can be driven LOW to put the GPS in standby for power savings.
- **PPS pin:** 1 pulse-per-second output for precision timing. Not used by current firmware (no free GPIO on the Feather). Can be connected on a carrier board for future use.
- **External antenna:** Connect via the uFL connector on the breakout. An active antenna is recommended for flights inside composite or fiberglass airframes.

## NMEA Sentence Parsing

The driver parses two NMEA sentence types:

### GGA - Position and Fix Quality

```
$GPGGA,123519,4807.038,N,01131.000,E,1,08,0.9,545.4,M,47.0,M,,*47
```

Extracted fields:
- UTC time (hour, minute, second, milliseconds)
- Latitude and longitude (DDDMM.MMMM format, converted to decimal degrees)
- Fix quality (0=none, 1=GPS, 2=DGPS)
- Number of satellites in use
- HDOP (horizontal dilution of precision)
- Altitude above mean sea level

### RMC - Speed, Heading, and Date

```
$GPRMC,123519,A,4807.038,N,01131.000,E,022.4,084.4,230394,003.1,W*6A
```

Extracted fields:
- Active/void status flag
- Ground speed (knots, converted to m/s using factor 0.514444)
- Track heading (degrees true)
- Date (day, month, year)

### Sentence Filtering

At initialization, the driver sends PMTK commands to configure the GPS:
- `PMTK220,1000` - Set 1 Hz update rate
- `PMTK314,0,1,0,1,0,0,0,0,0,0,0,0,0,0,0,0,0,0,0` - Output only GGA and RMC sentences

This reduces UART traffic and processing overhead.

## Coordinate Conversion

NMEA coordinates are in `DDDMM.MMMM` format (degrees and decimal minutes). The driver converts to decimal degrees:

```
decimal_degrees = degrees + (minutes / 60.0)
```

South latitudes and West longitudes are negated.

For telemetry transmission and flash storage, coordinates are stored as microdegrees (degrees * 1,000,000) in int32 format, providing ~0.11m resolution.

## Fix Validity and Timeout

The GPS data includes validity tracking:

| Field | Description |
|---|---|
| `pValid` | true when fix quality >= GPS fix |
| `pLastFixTimeMs` | System timestamp of last valid GGA sentence |
| `pAge` | Milliseconds since last valid fix |

A fix is invalidated if the age exceeds `GPS_FIX_TIMEOUT_MS` (3 seconds). This prevents stale coordinates from being used if the GPS loses satellite lock.

## Data Structure

```c
typedef struct
{
  float pLatitude ;         // Decimal degrees (+ = North)
  float pLongitude ;        // Decimal degrees (+ = East)
  float pAltitudeMsl ;      // Altitude MSL (meters)

  float pSpeedKnots ;       // Ground speed (knots)
  float pSpeedMps ;         // Ground speed (m/s)
  float pHeadingDeg ;       // Track heading (0-360)

  GpsFixQuality pFixQuality ;
  uint8_t pSatellites ;
  float pHdop ;

  uint8_t pHour, pMinute, pSecond ;
  uint16_t pMilliseconds ;
  uint8_t pDay, pMonth ;
  uint16_t pYear ;

  bool pValid ;
  uint32_t pLastFixTimeMs ;
  uint32_t pAge ;
} GpsData ;
```

## Fix Quality Levels

| Value | Name | Description |
|---|---|---|
| 0 | None | No fix |
| 1 | GPS | Standard GPS fix |
| 2 | DGPS | Differential GPS |
| 3 | PPS | Precise Positioning Service |
| 4 | RTK | Real-Time Kinematic |
| 5 | Float RTK | Float RTK solution |
| 6 | Estimated | Dead reckoning |
| 7 | Manual | Manual input |
| 8 | Simulation | Simulation mode |

## Integration with Flight System

### Telemetry
GPS data is included in every telemetry packet:
- Latitude/longitude as microdegrees (int32)
- Ground speed as cm/s (int16)
- Heading as degrees * 10 (uint16)
- Satellite count (uint8)
- GPS fix flag in status flags byte (bit 4)

### Flash Storage
GPS data recorded with each flight sample at 10 Hz:
- Launch coordinates stored in flight header (set at BOOST entry)
- Per-sample GPS: lat, lon, speed, heading, satellite count

### Display
GPS status shown on multiple OLED screens:
- Live screen: satellite count and fix indicator
- GPS Status screen: coordinates, speed, heading, satellite count, fix quality

### Main Loop
GPS is updated at 100 Hz in the main sensor read loop:
```c
if (sGpsOk)
{
  GPS_Update(theCurrentMs) ;
}
```

The `GPS_Update()` function reads all available UART bytes (non-blocking), buffers partial sentences, and processes complete NMEA sentences. At 9600 baud with 1 Hz updates, each update produces ~160 bytes of NMEA data.

## Checksum Verification

Every NMEA sentence includes an XOR checksum after the `*` delimiter. The driver verifies this checksum before processing:

```c
uint8_t theChecksum = 0 ;
// XOR all characters between $ and *
while (*ptr && *ptr != '*')
  theChecksum ^= *ptr++ ;
```

Sentences with invalid checksums are silently dropped.

## Sending Commands

The driver can send PMTK commands to the GPS module:

```c
GPS_SendCommand("PMTK220,500") ;  // Set 2 Hz update rate
```

The function automatically wraps the command with `$`, calculates the XOR checksum, and appends `*XX\r\n`.

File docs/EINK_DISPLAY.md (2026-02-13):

# eInk Display: Dual-Core Architecture and Partial Refresh

## Overview

The flight computer supports an optional UC8151D 2.9" flexible monochrome eInk display (296x128 pixels, Adafruit PID 4262) as an alternative to the SSD1306 OLED FeatherWing. The eInk display presents a unique challenge: full refresh takes 2-3 seconds, which would block LoRa telemetry (10 Hz) and sensor reads on the main loop. The solution uses RP2040 dual-core architecture to run the display independently on core1.

Build with `-DDISPLAY_EINK=1` in CMakeLists.txt to enable eInk mode.

---

## Hardware

| Parameter | Value |
|---|---|
| Display | Adafruit 2.9" Flexible 296x128 Monochrome eInk (PID 4262) |
| Controller | UC8151D |
| Interface | Bit-banged SPI on GP24 (SCK) / GP25 (MOSI) |
| Control Pins | CS (GP9), DC (GP10), RESET (GP11), BUSY (GP13) |
| Orientation | Landscape 296x128, ribbon cable on left (180° rotation) |
| Buffer Size | 4,736 bytes (128 wide x 296 tall, 1 bit per pixel) |

The eInk display uses **dedicated GPIO pins** for bit-banged SPI, completely separate from the LoRa radio's hardware SPI1 (GP14/GP15). This eliminates bus contention between cores.

### BUSY Pin

The BUSY pin (GP13) signals when the display is ready (high) or processing (low). The driver checks BUSY with a 200ms timeout; if the pin doesn't respond (hardware issue on some boards), it falls back to a fixed delay (3s for full refresh, 500ms for partial refresh).

---

## Dual-Core Architecture

### Core Assignment

| Core | Responsibilities |
|---|---|
| Core 0 | Sensors, flight state machine, LoRa telemetry (10 Hz), GPS, heartbeat LED, flash storage |
| Core 1 | eInk display rendering and refresh (can block freely for seconds) |

### Why Dual-Core?

eInk refresh blocks for 500ms-3s depending on refresh type. On a single core, this would starve LoRa telemetry and sensor reads. Moving the display to core1 allows it to block independently while core0 continues real-time operations uninterrupted.

### Inter-Core Communication

Communication between cores uses a **lock-free** design. No mutexes, no shared alarm pool, no printf from core1.

```
Core 0 (writes)                    Core 1 (reads)
─────────────────                  ─────────────────
sDisplayShared ──────────────────> theData = sDisplayShared
  (struct copy)                      (lock-free copy)

sBtnCycleMode  ──────────────────> read + clear flag
sBtnHome       ──────────────────> read + clear flag
sBtnEditRocket ──────────────────> read + clear flag

                                   sCore1CurrentMode ──> Core 0 reads
                                   sCore1Iterations  ──> Core 0 reads
```

**DisplaySharedData** struct contains all telemetry values (altitude, velocity, pressure, temperature, GPS, LoRa status, flight state, etc.). Core0 writes it unconditionally every main loop iteration (~1 kHz). Core1 reads it every display update cycle (~0.5 Hz). Torn reads are harmless — worst case, one frame shows a mix of old/new values, imperceptible on eInk.

**Button events** use individual `volatile bool` flags. Core0 sets them on button press; core1 reads and clears them.

**Display mode** feedback uses a `volatile DisplayMode` that core1 writes and core0 reads (for Button B context-dependent behavior).

### RP2040 Safety Rules

The RP2040's Cortex-M0+ has no cache and no out-of-order execution, so `volatile` alone guarantees memory coherence between cores. However, two Pico SDK mechanisms create hidden inter-core dependencies:

1. **Alarm Pool Deadlock**: `sleep_ms()` and `sleep_us()` use a shared alarm pool backed by hardware spin lock `PICO_SPINLOCK_ID_TIMER`. The alarm pool's IRQ fires on core0. When core1 calls `sleep_ms()`, it registers an alarm dependent on core0's timer IRQ — if core0 is busy, core1 hangs waiting for its alarm. **Fix**: Use `busy_wait_us_32()` for ALL timing on core1 and in any core0 code that could contend.

2. **USB CDC Printf Deadlock**: `printf` uses an internal mutex. The USB IRQ handler runs on core0. If core1 holds the printf mutex, core0 can't service the USB IRQ to drain the buffer, so core1's printf never completes — both cores deadlock. **Fix**: Never call printf from core1. Use `sCore1Iterations` counter for debug monitoring from core0.

**Files with busy_wait fixes**: `uc8151d.c`, `lora_radio.c` (TX polling loop), `heartbeat_led.c` (SendColor).

---

## Display Driver (uc8151d.c)

### Initialization

The UC8151D init sequence runs on core0 before core1 launches:

1. Triple hardware reset (per Adafruit driver reference)
2. Power settings (0x01): VDS=3.3V, VDG=internal, VCOM=2B/2B
3. Booster soft start (0x06): phase A/B/C = 0x17
4. Power on (0x04) + wait for BUSY
5. Panel setting (0x00): **0x1F for monochrome** (not 0xCF which is tri-color)
6. VCOM and data interval (0x50): 0x97
7. PLL clock (0x30): 0x29
8. Resolution (0x61): 128 wide x 296 tall
9. VCM DC setting (0xBD): 0x0A

### Coordinate System

The physical display is landscape (296 wide x 128 tall) but the UC8151D controller uses portrait orientation (128 wide x 296 tall). A 180° rotation is applied because the ribbon cable is on the left:

```
Physical (landscape)         Controller (portrait)
+------------------+         +--------+
|                  |         |        |
| (0,0)    (295,0) |   →     | row 295|  row = (295 - physX)
|                  |         |  ...   |
| (0,127) (295,127)|         | row 0  |
+------------------+         +--------+
  ribbon cable (left)        16 bytes/row
```

**Pixel mapping** (framebuffer.c):
```c
buffer_row = (295 - physical_X)
byte_index = physical_Y / 8
bit_index  = 7 - (physical_Y % 8)     // MSB first
offset     = buffer_row * 16 + byte_index
```

### Full Refresh

`UC8151D_WriteImage()` sends the entire 4,736-byte framebuffer as DTM2 (new data), then triggers refresh. Takes ~3 seconds with BUSY wait.

### Partial Refresh

`UC8151D_WritePartial()` updates a rectangular region without redrawing the entire screen. Takes ~500ms. Requires both old data (DTM1) and new data (DTM2) — the display uses the difference to compute the optimal waveform.

```
Partial Refresh Sequence:
1. PTIN (0x91)           — Enter partial mode
2. PTL  (0x90)           — Set partial window (H start/end, V start/end, scan mode)
3. DTM1 (0x10)           — Send OLD data for the region
4. DTM2 (0x13)           — Send NEW data for the region
5. DRF  (0x12)           — Trigger refresh
6. Wait for BUSY/delay   — Display processes the update
7. PTOUT (0x92)          — Exit partial mode
```

The partial window coordinates must be **byte-aligned** horizontally (H values rounded to 8-pixel boundaries).

---

## Partial Refresh Strategy (eink_display.c)

### Refresh Hierarchy

The display uses progressively larger refresh regions depending on what changed:

| Level | Region Size | When Used |
|---|---|---|
| Per-digit | 12x16 px | Individual digit changed (same string length) |
| Per-box | ~100x16 px | String length changed (value got longer/shorter) |
| Content area | 296x96 px | Screens that redraw all content (LoRa, GPS) |
| Full refresh | 296x128 px | Every 50 updates, or when switching screens |

### Per-Digit Refresh (RefreshValue)

The core optimization. For each displayed value (altitude, velocity, pressure, etc.):

1. Compare old string with new string character by character
2. **Same length**: For each changed character, clear its 12x16 cell in the framebuffer, draw the new character, and `UC8151D_WritePartial()` just that cell
3. **Different length**: Clear the full column box (~100x16), redraw the value + unit, and `UC8151D_WritePartial()` the box

```
Example: altitude changes from "12.3" to "12.5"

  "12.3"  vs  "12.5"
   ││││       ││││
   ====       ==!= ← only position 3 differs

  → Clear 12x16 cell at digit position 3
  → Draw '5' in framebuffer
  → WritePartial for 12x16 region only
```

This minimizes data transfer (~24 bytes vs 4,736 for full refresh) and reduces ghosting on unchanged pixels.

### Double Buffering

Two 4,736-byte framebuffers maintain display state:

- **sFrameBuffer**: Working buffer — all drawing happens here
- **sPrevBuffer**: Previous display state — used as "old data" for partial refresh

**Critical rule**: `memcpy(sPrevBuffer, sFrameBuffer)` must happen **after** all `UC8151D_WritePartial()` calls in an update cycle, never before. This ensures sPrevBuffer always reflects what was last sent to the display.

```
Update Cycle:
1. RefreshValue() modifies sFrameBuffer + calls WritePartial(sPrevBuffer, sFrameBuffer, ...)
2. RefreshValue() for next value (same pattern)
3. memcpy(sPrevBuffer, sFrameBuffer)  ← sync AFTER all writes
```

### Full Refresh Interval

Every 50 updates (~100 seconds at 2s interval), a full refresh clears accumulated eInk ghosting. The full refresh redraws the entire screen layout (header, labels, values, separators, footer) and uses `UC8151D_WriteImage()`.

---

## Display Screens

### Layout (296x128 landscape)

```
+--[ROCKET AVIONICS  IDLE]--[R:1  GPS:--]--+  ← Header (inverted, 14px)
|  ALTITUDE        VELOCITY                 |  ← Labels (y=20)
|  12.3 m          0.0 m/s                  |  ← Values (y=32, scale 2)
|──────────────────────────────────────────|  ← Separator (y=52)
|  GATEWAY         GPS                      |  ← Labels (y=56)
|  Good            Fix 8                    |  ← Values (y=72, scale 2)
|──────────────────────────────────────────|  ← Separator (y=92)
+--[v2.0.0  26-02-12]─────────────────────+  ← Footer (inverted, 14px)
```

### Available Modes

| Mode | Content | Refresh Strategy |
|---|---|---|
| Live | Altitude, velocity, gateway, GPS | Per-digit |
| Sensors | Pressure, temperature, altitude | Per-digit |
| LoRa Status | Link, RSSI, TX/RX packet counts | Content area |
| GPS Status | Fix, satellites, lat/lon, speed | Content area |
| Rocket ID | ID number (editable via Button B) | Content area |
| Device Info | Firmware, sensor status | Full (static) |
| About | Version, copyright | Full (static) |
| Armed | "READY FOR LAUNCH" | Full (static) |
| Flight Complete | Max altitude, velocity, times | Full (static) |

### Button Navigation

- **Button A**: Cycle through display modes
- **Button B**: On Rocket ID screen → cycle ID (0-15); on all other screens → return to Live

### Flight Behavior

During active flight (Boost through Descent), core1 skips display updates entirely to avoid any potential interference. The display resumes updating after landing.

---

## Core1 Display Loop

The display loop runs continuously on core1 after launch:

```
Core1_DisplayLoop:
  while (1):
    1. Copy sDisplayShared from core0 (lock-free struct copy)
    2. Read/clear button event flags
    3. Process button events (cycle mode, go home)
    4. Skip display during active flight (Boost..Descent)
    5. Call appropriate StatusDisplay_* function based on mode
    6. Wait 2 seconds (busy_wait_us_32) before next update
       - 5 seconds in LANDED/COMPLETE state
       - 200ms after button press (responsive mode switch)
```

No printf, no sleep_ms, no mutexes — fully independent from core0.

---

## File Reference

| File | Purpose |
|---|---|
| `src/uc8151d.c` | UC8151D driver: init, clear, full/partial refresh, sleep |
| `include/uc8151d.h` | Display constants, command definitions, function declarations |
| `src/framebuffer.c` | Pixel/line/rect/text drawing with coordinate rotation |
| `include/framebuffer.h` | Framebuffer API |
| `include/font5x7.h` | 5x7 pixel font bitmap (ASCII 32-126) |
| `src/eink_display.c` | All display screens, per-digit refresh logic, mode management |
| `src/main.c` | Core1 launch, DisplaySharedData, Core1_DisplayLoop |
| `include/pins.h` | eInk GPIO pin definitions, update intervals |

---

## Troubleshooting

| Symptom | Cause | Fix |
|---|---|-----|
| Display never updates after boot | Core1 deadlock from sleep_ms or printf | Ensure all core1 code paths use busy_wait_us_32, no printf |
| Display shows stale values | sPrevBuffer synced before WritePartial | Move memcpy(sPrevBuffer, sFrameBuffer) to AFTER all WritePartial calls |
| Both cores hang after 1-2 display updates | Alarm pool contention via sleep_ms/sleep_us | Replace with busy_wait_us_32 in uc8151d.c, lora_radio.c, heartbeat_led.c |
| Partial refresh shows ghosting | Normal eInk behavior | Full refresh every 50 updates clears it; reduce interval if needed |
| Display blank / no init | SPI pin conflict or init failure | Verify GP24/GP25 not used elsewhere; check init printf output |
| BUSY pin timeout messages | Pin not connected or floating | Normal — driver falls back to fixed delays automatically |

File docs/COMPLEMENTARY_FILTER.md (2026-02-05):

# Complementary Filter Tuning Guide

## Overview

The flight computer uses a complementary filter to fuse barometer altitude data (accurate but slow) with IMU accelerometer data (fast but drifty) to produce smooth, responsive altitude and velocity estimates. This document explains how the filter works and how to tune it for different rockets.

Source: `firmware_flight/src/flight_control.c`

## How It Works

The filter maintains three state variables:
- **Altitude** (`pCfAltitudeM`) - estimated altitude in meters
- **Velocity** (`pCfVelocityMps`) - estimated vertical velocity in m/s
- **Accel Bias** (`pCfAccelBiasMps2`) - learned accelerometer offset in m/s^2

### Two-Step Update Cycle

The filter runs in two steps every loop iteration:

#### Step 1: IMU Prediction (100 Hz)

When new IMU data arrives, integrate acceleration to update velocity and altitude:

```
vertical_accel = (accelZ - 1.0) * 9.80665 - bias
velocity += vertical_accel * dt
altitude += velocity * dt
```

The IMU provides fast response to acceleration changes but drifts over time due to sensor noise and bias.

#### Step 2: Barometric Correction (100 Hz)

When new barometric data arrives, correct the filter state toward the barometric truth:

```
error = smoothed_baro_altitude - filter_altitude

velocity += Kv * error * dt
altitude += Ka * error * dt
bias     -= Kb * error * dt
```

The barometer provides accurate absolute altitude but responds slowly to rapid changes.

### Bias Estimation

The bias term continuously learns the accelerometer's DC offset. At rest, if the accelerometer reads slightly more or less than 1.0g, the bias integrator slowly adjusts to cancel this error. This happens through the negative feedback loop:

```
bias -= Kb * altitude_error * dt
```

When the filter altitude drifts above the barometric altitude (positive error), the bias increases, which reduces the next acceleration integration, bringing the altitude back down.

## Current Gain Settings

Defined in `flight_control.c`:

| Gain | Symbol | Value | Unit |
|---|---|---|---|
| Altitude correction | `kCfGainAltitude` | 6.0 | 1/s |
| Velocity correction | `kCfGainVelocity` | 10.0 | 1/s^2 |
| Bias learning rate | `kCfGainBias` | 1.0 | 1/s^3 |
| Max integration dt | `kCfMaxDtS` | 0.05 | seconds |

The altitude smoothing applied to the barometric input before it enters the filter:

| Parameter | Value | Effect |
|---|---|---|
| `kAltitudeSmoothingAlpha` | 0.1 | ~2 Hz cutoff at 100 Hz sample rate |

## Tuning Guide

### Crossover Frequency

The gains determine where the filter transitions from trusting the IMU (high frequency) to trusting the barometer (low frequency). The current settings give a crossover around 0.5 Hz, meaning:
- Events faster than ~2 seconds: dominated by IMU
- Events slower than ~2 seconds: dominated by barometer

### Making the Filter More Responsive (Higher Crossover)

Increase Ka and Kv to trust the barometer corrections more aggressively:

```c
#define kCfGainAltitude  10.0f   // was 6.0
#define kCfGainVelocity  16.0f   // was 10.0
```

**When to use:** Slow-burning motors with gradual acceleration changes; rockets where barometric noise is low (larger rockets with better aerodynamic stability).

**Trade-off:** The filter responds faster to barometric changes but becomes noisier if the barometer has turbulence-induced pressure fluctuations during flight.

### Making the Filter Smoother (Lower Crossover)

Decrease Ka and Kv to rely more on IMU integration:

```c
#define kCfGainAltitude  3.0f    // was 6.0
#define kCfGainVelocity  5.0f    // was 10.0
```

**When to use:** High-thrust motors with sharp acceleration spikes; situations where barometric readings may be noisy (small rockets with turbulent airflow over the sensor port).

**Trade-off:** Smoother output but the velocity estimate may drift further from truth during long coast phases.

### Bias Learning Rate

The bias gain controls how quickly the filter learns the accelerometer's DC offset:

- **Higher Kb (e.g., 2.0):** Faster convergence on pad, but may track non-bias errors during flight (e.g., interpreting wind gusts as bias)
- **Lower Kb (e.g., 0.5):** Slower convergence, more stable during flight but takes longer to settle after power-on
- **Current Kb (1.0):** Good compromise; converges within ~10 seconds on the pad

The bias is preserved across the arm command, so it should be well-converged before arming.

### Altitude Smoothing Alpha

The barometric altitude is smoothed with an exponential moving average before entering the filter:

```c
smoothed = alpha * raw + (1 - alpha) * smoothed
```

- **Higher alpha (e.g., 0.3):** Less smoothing, barometer changes reach filter faster, but more noise
- **Lower alpha (e.g., 0.05):** More smoothing, cleaner barometric input, but slower response
- **Current (0.1):** ~2 Hz cutoff at 100 Hz, good balance for most flights

## Baro-Only Fallback

If the IMU is not available (initialization failed or not present), the filter falls back to pure barometric velocity estimation:

```c
velocity = alpha * instantaneous + (1 - alpha) * previous
```

Where:
- `kVelocitySmoothingAlpha` = 0.15
- `instantaneous = (alt_current - alt_previous) / dt`

This provides usable velocity but with more noise and latency than the fused estimate.

## Practical Tips

### Before First Flight

1. Power on the flight computer on the pad
2. Wait 10+ seconds for the accel bias to converge (visible as stable near-zero velocity on the idle display)
3. Arm the rocket
4. Do not move the rocket after arming (ground reference is captured at arm time)

### Verifying Filter Health

In telemetry data, check:
- **Velocity near zero at rest** (< 0.1 m/s) - indicates good bias convergence
- **Altitude near zero at rest** (< 0.5 m) - indicates filter is tracking barometer
- **Smooth velocity profile** during flight - no sudden jumps or oscillations

### Interpreting dt Clamping

The filter clamps dt to 50ms (`kCfMaxDtS`). If the actual dt exceeds this (e.g., after a pause in sensor reads), the excess time is discarded to prevent large integration jumps. This should not happen during normal flight operation.

## Mathematical Background

The complementary filter is equivalent to a second-order observer for the system:

```
State: [altitude, velocity, bias]
Prediction: double integration of (measured_accel - bias - gravity)
Correction: proportional feedback from barometric altitude error

d/dt [alt]  = vel
d/dt [vel]  = accel_measured - g - bias
d/dt [bias] = 0  (slowly varying)

Correction terms:
alt  += Ka * (baro_alt - filter_alt) * dt
vel  += Kv * (baro_alt - filter_alt) * dt
bias -= Kb * (baro_alt - filter_alt) * dt
```

The gains Ka, Kv, Kb determine the observer poles. For a critically-damped response at crossover frequency w_c:
- Ka ~ 2 * w_c
- Kv ~ w_c^2
- Kb ~ w_c^3 (very slow, for bias only)

With the current gains (Ka=6, Kv=10), the crossover is approximately w_c ~ 3 rad/s (~0.5 Hz).

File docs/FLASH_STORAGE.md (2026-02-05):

# Flash Storage Format

## Overview

Flight data is stored in the RP2040's onboard 8MB flash memory. The last 512KB is reserved for flight storage, organized into an index sector and 7 flight slots of 64KB each. Data is buffered in RAM during flight and written to flash after landing.

Source: `firmware_flight/src/flight_storage.c`, `firmware_flight/include/flight_storage.h`

## Memory Layout

```
Flash Address    Offset       Size    Contents
─────────────────────────────────────────────────────
0x10000000       0x000000     ~7.5MB  Firmware (program + data)
    ...
0x10780000       0x780000     64KB    Flight Slot 0
0x10790000       0x790000     64KB    Flight Slot 1
0x107A0000       0x7A0000     64KB    Flight Slot 2
0x107B0000       0x7B0000     64KB    Flight Slot 3
0x107C0000       0x7C0000     64KB    Flight Slot 4
0x107D0000       0x7D0000     64KB    Flight Slot 5
0x107E0000       0x7E0000     64KB    Flight Slot 6
0x107FE000       0x7FE000     4KB     Flight Index
0x107FF000       0x7FF000     4KB     Calibration / Settings
```

Total storage area: 512KB (`kFlightStorageSize = 0x80000`)

## Constants

| Constant | Value | Description |
|---|---|---|
| `kFlashTotalSize` | 0x800000 (8MB) | Total flash on Feather RP2040 |
| `kFlightStorageSize` | 0x80000 (512KB) | Reserved for flight data |
| `kFlightStorageOffset` | 0x780000 | Start of flight storage |
| `kFlightSlotSize` | 0x10000 (64KB) | Size per flight slot |
| `kMaxStoredFlights` | 7 | Maximum stored flights |
| `kFlightIndexOffset` | 0x7FE000 | Index sector offset |
| `kCalibrationOffset` | 0x7FF000 | Settings/calibration sector |
| `FLASH_SECTOR_SIZE` | 4096 (4KB) | Flash erase granularity |
| `FLASH_PAGE_SIZE` | 256 | Flash program granularity |
| `kMaxSamplesPerFlight` | 1200 | Buffer limit (~120 seconds at 10 Hz) |

## Flight Index

The index sector tracks which slots are in use and the next flight ID.

```
Offset  Size    Field
──────────────────────────────────
0       4       Magic (0x58444E49 = "INDX")
4       4       Version (1)
8       4       Next flight ID (uint32)
12      7       Slot usage flags (1 byte per slot, 0=free, 1=used)
19      4       Checksum (sum of bytes 0-18)
```

The index is stored in the first 256-byte page of its 4KB sector. The entire sector is erased and rewritten on every update.

## Flight Header (80 bytes)

Each flight slot begins with a header in the first flash page (256 bytes):

```c
typedef struct __attribute__((packed))
{
  uint32_t pMagic ;             // 0x54484746 ("FGHT")
  uint32_t pVersion ;           // 1
  uint32_t pFlightId ;          // Sequential flight ID
  uint32_t pTimestamp ;         // Unix timestamp (if available)
  uint32_t pSampleCount ;      // Number of samples recorded

  float pMaxAltitudeM ;         // Peak altitude (meters AGL)
  float pMaxVelocityMps ;       // Peak velocity (m/s)
  uint32_t pApogeeTimeMs ;      // Time to apogee from launch
  uint32_t pFlightTimeMs ;      // Total flight duration (ms)
  float pGroundPressurePa ;     // Ground reference pressure

  int32_t pLaunchLatitude ;     // GPS latitude (microdegrees)
  int32_t pLaunchLongitude ;    // GPS longitude (microdegrees)

  uint8_t pReserved[20] ;       // Reserved for future use
  uint32_t pChecksum ;          // Sum of all preceding bytes
} FlightHeader ;                // 80 bytes
```

## Flight Sample (52 bytes)

Samples are stored sequentially starting at the second flash page (offset 256 within the slot):

```c
typedef struct __attribute__((packed))
{
  uint32_t pTimeMs ;            // Time since launch (ms)

  int32_t pAltitudeCm ;         // Altitude in centimeters
  int16_t pVelocityCmps ;       // Velocity in cm/s
  uint32_t pPressurePa ;        // Pressure in Pascals
  int16_t pTemperatureC10 ;     // Temperature * 10

  int32_t pGpsLatitude ;        // Latitude (microdegrees)
  int32_t pGpsLongitude ;       // Longitude (microdegrees)
  int16_t pGpsSpeedCmps ;       // Ground speed in cm/s
  uint16_t pGpsHeadingDeg10 ;   // Heading * 10
  uint8_t pGpsSatellites ;      // Satellite count

  int16_t pAccelX ;             // Accelerometer X (milli-g)
  int16_t pAccelY ;             // Accelerometer Y (milli-g)
  int16_t pAccelZ ;             // Accelerometer Z (milli-g)

  int16_t pGyroX ;              // Gyroscope X (0.1 dps)
  int16_t pGyroY ;              // Gyroscope Y (0.1 dps)
  int16_t pGyroZ ;              // Gyroscope Z (0.1 dps)

  int16_t pMagX ;               // Magnetometer X (milligauss)
  int16_t pMagY ;               // Magnetometer Y (milligauss)
  int16_t pMagZ ;               // Magnetometer Z (milligauss)

  uint8_t pState ;              // Flight state
} FlightSample ;                // 52 bytes
```

## Capacity

| Metric | Value |
|---|---|
| Bytes per sample | 52 |
| Samples per 64KB slot | ~1,230 (64,000 / 52) |
| RAM buffer limit | 1,200 samples |
| Max recording time | 120 seconds at 10 Hz |
| Typical 60s flight | 600 samples = ~31 KB |
| Typical 30s flight | 300 samples = ~16 KB |

## Recording Lifecycle

### 1. Start Recording (launch detected)

```
FlightStorage_StartFlight(groundPressure, launchLat, launchLon)
```

- Find first free slot in index
- Initialize header with flight ID, ground pressure, GPS launch coordinates
- Reset RAM sample buffer
- Returns flight ID (0 if storage full)

### 2. Log Samples (during flight, 10 Hz)

```
FlightStorage_LogSample(&sample)
```

- Copies sample to RAM buffer (`sSampleBuffer[]`)
- Increments sample count
- Returns false if buffer full (>1200 samples)
- No flash writes during flight (all in RAM)

### 3. End Recording (landing detected)

```
FlightStorage_EndFlight(maxAlt, maxVel, apogeeTime, flightTime)
```

- Updates header with flight results
- Calculates header checksum
- Erases required flash sectors (only sectors needed, not entire slot)
- Writes header to first page
- Writes samples page-by-page (256 bytes per page)
- Updates index: marks slot as used, increments next flight ID
- All flash operations done with interrupts disabled

## Flash Write Safety

Flash operations disable all interrupts to prevent corruption:

```c
uint32_t theInterrupts = save_and_disable_interrupts() ;
flash_range_erase(offset, size) ;
flash_range_program(offset, data, FLASH_PAGE_SIZE) ;
restore_interrupts(theInterrupts) ;
```

This means:
- No LoRa communication during flash writes
- No sensor reads during flash writes
- Writes only happen after landing, so flight safety is unaffected
- Erase is done in minimum sectors needed (4KB granularity)

## LoRa Download Protocol

Flight data can be downloaded wirelessly via LoRa commands:

### List Flights (`kCmdFlashList` = 0x20)

Response packet (`kLoRaPacketStorageList` = 0x06):
```
magic(1), type(1), count(1), then per flight:
  slot(1), flightId(4), maxAltCm(4), flightTimeMs(4), sampleCount(4)
```

### Read Flight Header (`kCmdFlashRead` = 0x21, startSample = 0xFFFFFFFF)

Response packet (`kLoRaPacketStorageData` = 0x07):
```
magic(1), type(1), slot(1), startSample=0xFFFFFFFF(4), headerData(80)
```

### Read Flight Samples (`kCmdFlashRead` = 0x21)

Request: `slot(1), startSample(4)`

Response packet: 3 samples per packet (52 bytes each = 156 bytes data):
```
magic(1), type(1), slot(1), startSample(4), totalSamples(4), count(1), samples(N*52)
```

### Delete Flight (`kCmdFlashDelete` = 0x22)

- Single slot: `slot(1)` - erases 64KB and updates index
- All flights: `slot = 0xFF` - erases all used slots

## Rocket ID and Name Storage

The calibration sector (0x7FF000) stores persistent settings via the `storage.c` module:
- Rocket ID (0-15): stored as single byte
- Rocket name: stored as null-terminated string (max `kRocketNameMaxLen`)
- Both persist across power cycles and firmware updates

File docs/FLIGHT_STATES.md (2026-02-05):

# Flight State Machine

## Overview

The flight computer uses a finite state machine to manage the flight lifecycle from pre-launch through landing and data recovery. The state machine runs in the main loop at 1 kHz and makes transition decisions based on altitude, velocity, and timing data from the sensor fusion system.

Source: `firmware_flight/src/flight_control.c`

## State Diagram

```
               arm cmd
  IDLE ──────────────────► ARMED
   ▲                         │
   │ reset cmd               │ alt > 10m OR vel > 10 m/s
   │                         ▼
COMPLETE                   BOOST
   ▲                         │
   │ download                │ vel < 95% of max AND alt > 20m
   │                         ▼
LANDED ◄──── DESCENT ◄── COAST
   5s stationary    ▲        │
   vel < 1 m/s      │        │ vel < 2 m/s for 3 consecutive samples
   alt < 10m         │        ▼
                    APOGEE ──┘
                  (immediate transition)
```

## States

### IDLE (0)
- **Entry:** Power-on or after reset command
- **Behavior:** Sensors read and displayed; first valid pressure used as temporary ground reference for display; telemetry sent at 0.5 Hz
- **Exit:** Arm command received via LoRa

### ARMED (1)
- **Entry:** Arm command accepted (only from IDLE or COMPLETE)
- **Behavior:** Ground pressure and temperature recorded as reference; altitude/velocity counters reset; complementary filter altitude and velocity zeroed (but accel bias preserved); telemetry sent at 2 Hz
- **Exit:** Launch detected (altitude > 10m OR velocity > 10 m/s)

### BOOST (2)
- **Entry:** Launch detection threshold exceeded
- **Behavior:** Launch timestamp recorded; telemetry enabled at 10 Hz; flash recording started; max velocity tracked; flight results initialized
- **Exit:** Velocity drops below 95% of recorded max velocity AND altitude > 20m

### COAST (3)
- **Entry:** Motor burnout detected
- **Behavior:** Max altitude tracked; apogee descent counter monitored; telemetry continues at 10 Hz
- **Exit:** Velocity < 2 m/s for 3 consecutive samples (`kApogeeDescendCount`)

### APOGEE (4)
- **Entry:** Apogee detected
- **Behavior:** Apogee altitude and time recorded in flight results; immediate transition to DESCENT (single-frame state)
- **Exit:** Immediate transition to DESCENT

### DESCENT (5)
- **Entry:** Apogee recorded
- **Behavior:** Stationary counter tracks consecutive low-velocity samples; telemetry continues at 10 Hz
- **Exit:** |velocity| < 1 m/s AND altitude < 10m for 50 consecutive samples (5 seconds at 10 Hz)

### LANDED (6)
- **Entry:** Landing detected
- **Behavior:** Flight time and sample count finalized; flash recording ended; telemetry reduced to 1 Hz
- **Exit:** Download command transitions to COMPLETE

### COMPLETE (7)
- **Entry:** Flight data downloaded
- **Behavior:** Telemetry at 1 Hz; ready for reset
- **Exit:** Reset command returns to IDLE
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

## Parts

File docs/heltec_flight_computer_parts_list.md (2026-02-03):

# Heltec Flight Computer Parts List

Lower-cost flight computer using Heltec Wireless Tracker with external sensors.

## Core Components

| Component | Description | Price | Link |
|---|---|---|---|
| Heltec Wireless Tracker | ESP32-S3 + SX1262 + GPS + Display | $26.90 | [heltec.org](https://heltec.org/project/wireless-tracker/) |
| **Adafruit BMP581** | High-accuracy barometer ±3.3cm (Recommended) | $9.95 | [adafruit.com/product/5857](https://www.adafruit.com/product/5857) |
| **Adafruit ICM-20649** | Wide-range IMU ±30g, ±4000dps (Recommended) | $14.95 | [adafruit.com/product/4464](https://www.adafruit.com/product/4464) |
| LiPo Battery 3.7V 500mAh | Power source | $7.95 | [adafruit.com/product/258](https://www.adafruit.com/product/258) |

**Core Components Subtotal:** ~$60

## Why BMP581?

The BMP581 is the recommended barometer for rocket flight computers:

| Spec | BMP581 | BMP390 |
|---|---|---|
| Accuracy | **±0.4 Pa (±3.3cm)** | ±3 Pa (±25cm) |
| Max ODR | **240 Hz** | 200 Hz |
| Noise | **1 cm** | 10 cm |
| Price | **$9.95** | $12.50 |

**Benefits:**
- **7.5x better altitude accuracy** - Critical for precise apogee detection
- **Lower noise** - Cleaner velocity calculations for deployment timing
- **Faster sampling** - Better response during rapid altitude changes
- **Cheaper** - Saves $2.55 per flight computer
- **Newer technology** - Capacitive sensing vs piezo-resistive

### Alternative: BMP390

If you already have BMP390 sensors:
- [Adafruit BMP390](https://www.adafruit.com/product/4816) - $12.50
- Firmware auto-detects and supports both sensors
- Still good performance for most rockets

## Why ICM-20649?

The ICM-20649 is the recommended IMU for rocket flight computers:

| Spec | ICM-20649 | LSM6DSOX |
|---|---|---|
| Accelerometer | **±30g** | ±16g |
| Gyroscope | **±4000 dps** | ±2000 dps |
| Price | **$14.95** | $19.95 |
| Magnetometer | No | Yes (with LIS3MDL) |

**Benefits:**
- **Won't clip during boost** - High-thrust motors (E-I class) can produce 20-30g
- **Handles fast spins** - If fins are canted or rocket tumbles
- **Cheaper** - Saves $5 per flight computer
- **Magnetometer not needed** - Parachute deployment is altitude-based, not heading-based

### Alternative: LSM6DSOX + LIS3MDL

If you need magnetometer data for heading/orientation:
- [LSM6DSOX + LIS3MDL 9-DoF](https://www.adafruit.com/product/4517) - $19.95
- Only use for low-power motors (A-D class) where g-forces stay under 16g

## Pyro Channel Components

| Component | Description | Qty | Est. Price |
|---|---|-----|---|
| IRLZ44N N-Channel MOSFET | Logic-level MOSFET for pyro firing | 2 | $2.00 |
| 1kΩ Resistor (1/4W) | MOSFET gate resistor | 2 | $0.20 |
| 10kΩ Resistor (1/4W) | Gate pull-down resistor | 2 | $0.20 |
| 2-Position Screw Terminal (5mm) | E-match connection | 2 | $1.50 |
| SPST Toggle Switch | Arm safety switch | 1 | $2.00 |

**Pyro Components Subtotal:** ~$6

## Wiring Supplies

| Component | Description | Est. Price |
|---|---|---|
| 26 AWG silicone wire | I2C and pyro connections | $5.00 |
| Heat shrink tubing | Wire protection | $3.00 |
| Solder | For Heltec edge connections | - |

**Wiring Subtotal:** ~$8

## Total Cost

| Category | Cost |
|---|---|
| Core Components (BMP581 + ICM-20649) | ~$60 |
| Pyro Components | ~$6 |
| Wiring Supplies | ~$8 |
| **Total** | **~$74** |

## Cost Comparison

| Item | RP2040 Flight Computer | Heltec Flight Computer | Savings |
|---|---|---|---|
| MCU + LoRa | $24.95 | $26.90 | - |
| GPS | $29.95 | Built-in | $29.95 |
| Display | $14.95 | Built-in | $14.95 |
| IMU | $19.95 | $14.95 (ICM-20649) | $5.00 |
| Barometer | $12.50 | $9.95 (BMP581) | $2.55 |
| Stacking board | $8.50 | N/A | $8.50 |
| Battery | $7.95 | $7.95 | - |
| Pyro | $6.00 | $6.00 | - |
| Wiring | $0 | $8.00 | -$8.00 |
| **Total** | **~$125** | **~$74** | **~$51 (41%)** |

## Wiring Diagram

```
Heltec Wireless Tracker (edge pads)
    │
    ├── GPIO 5 (SDA) ────┬──── BMP581 SDA
    │                    └──── ICM-20649 SDA
    │
    ├── GPIO 6 (SCL) ────┬──── BMP581 SCL
    │                    └──── ICM-20649 SCL
    │
    ├── GPIO 7 ──[1kΩ]──┬── MOSFET 1 Gate (Drogue)
    │                   │
    │                [10kΩ]
    │                   │
    │                  GND
    │
    ├── GPIO 45 ──[1kΩ]──┬── MOSFET 2 Gate (Main)
    │                    │
    │                 [10kΩ]
    │                    │
    │                   GND
    │
    ├── GPIO 2 ──── Pyro 1 Continuity Divider
    │
    ├── GPIO 4 ──── Pyro 2 Continuity Divider
    │
    ├── GPIO 46 ──── Arm Switch ──── GND
    │
    ├── 3.3V ────┬──── BMP581 VIN
    │            └──── ICM-20649 VIN
    │
    └── GND ─────┬──── BMP581 GND
                 └──── ICM-20649 GND
```

## Sensor I2C Addresses

Recommended sensors:
| Sensor | Address | Function |
|---|---|---|
| BMP581 | 0x47 | Barometric pressure (±3.3cm accuracy) |
| ICM-20649 | 0x68 | Accelerometer + Gyroscope (±30g, ±4000dps) |

Alternative sensors (auto-detected):
| Sensor | Address | Function |
|---|---|---|
| BMP390 | 0x77 | Barometric pressure (±25cm accuracy) |
| LSM6DSOX | 0x6A | Accelerometer + Gyroscope (±16g, ±2000dps) |
| LIS3MDL | 0x1E | Magnetometer |

All sensors share the same I2C bus (GPIO 5/6). Firmware auto-detects which sensors are connected.

## Assembly Notes

1. **Solder I2C wires to Heltec edge pads** (GPIO 5, 6, 3.3V, GND)
2. **Connect BMP581 via STEMMA QT** or solder directly
3. **Connect ICM-20649 via STEMMA QT** or solder directly
4. **Wire pyro channels** to GPIO 7, 45, 2, 4, 46
5. **Secure with heat shrink** and cable ties

## Form Factor

The Heltec is very compact (~50x25mm). The external sensors add bulk but the total package is still smaller than the Feather stack.

Suggested mounting:
- Heltec board oriented with display facing out
- BMP581 mounted nearby with port exposed to air
- ICM-20649 mounted rigidly to sense rocket motion
- Pyro terminals accessible for e-match connection

## Where to Buy

### Heltec
- **Heltec Official:** [heltec.org](https://heltec.org)
- **AliExpress:** Search "Heltec Wireless Tracker" (~$20-25)
- **Amazon:** Higher price but faster shipping

### Adafruit Components
- **Adafruit:** [adafruit.com](https://www.adafruit.com)

### Electronic Components
- **DigiKey:** [digikey.com](https://www.digikey.com)
- **Mouser:** [mouser.com](https://www.mouser.com)

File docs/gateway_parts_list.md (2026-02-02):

# Ground Gateway Parts List

Complete bill of materials for building the ground gateway. Two options are available: the Heltec Wireless Tracker (recommended) or an RP2040-based gateway.

## Option 1: Heltec Gateway (Recommended)

All-in-one solution with built-in WiFi, GPS, display, and LoRa radio.

| Component | Description | Price | Link |
|---|---|---|---|
| Heltec Wireless Tracker | ESP32-S3 + SX1262 LoRa + GPS + OLED | $26.90 | [heltec.org](https://heltec.org/project/wireless-tracker/) |
| 915MHz LoRa Antenna (SMA) | Included with board | - | - |
| USB-C Cable | Power and initial programming | $5.00 | - |
| LiPo Battery 3.7V 1000mAh (optional) | Portable operation | $8.00 | - |

**Heltec Gateway Total:** ~$32-40

### Heltec Features
- Built-in WiFi (AP mode or station mode)
- Built-in GPS (UC6580 module)
- Built-in 0.96" OLED display
- SX1262 LoRa radio (915 MHz)
- OTA firmware updates over WiFi
- mDNS discovery (`RocketGateway.local`)
- USB-C connector
- Compact form factor

### Heltec Notes
- The built-in GPS has a weak ceramic antenna - works outdoors but struggles indoors
- For reliable GPS, add an external active GPS antenna with IPEX/U.FL connector
- WiFi range is adequate for field use (~50-100m line of sight)

### Optional: External GPS Antenna

| Component | Description | Price | Link |
|---|---|---|---|
| Active GPS Antenna (28dB, IPEX) | External antenna for better reception | $12.00 | Amazon/AliExpress |

---

## Option 2: RP2040 Gateway

Modular Feather-based gateway with optional WiFi.

### Core Components

| Component | Adafruit Product | Price | Link |
|---|---|---|---|
| Feather RP2040 with RFM95 LoRa Radio (915MHz) | PID 5714 | $24.95 | [adafruit.com/product/5714](https://www.adafruit.com/product/5714) |
| FeatherWing OLED 128x64 Display | PID 4650 | $14.95 | [adafruit.com/product/4650](https://www.adafruit.com/product/4650) |
| LiPo Battery 3.7V 500mAh | PID 258 | $7.95 | [adafruit.com/product/258](https://www.adafruit.com/product/258) |

**RP2040 Core Total:** ~$48

### Optional: WiFi Support

| Component | Adafruit Product | Price | Link |
|---|---|---|---|
| AirLift FeatherWing (ESP32 WiFi) | PID 4264 | $12.95 | [adafruit.com/product/4264](https://www.adafruit.com/product/4264) |
| FeatherWing Tripler Mini Kit | PID 3417 | $8.50 | [adafruit.com/product/3417](https://www.adafruit.com/product/3417) |

**With WiFi Total:** ~$70

### Optional: GPS Support

| Component | Adafruit Product | Price | Link |
|---|---|---|---|
| Ultimate GPS FeatherWing | PID 3133 | $39.95 | [adafruit.com/product/3133](https://www.adafruit.com/product/3133) |

**With GPS Total:** ~$88 (or ~$110 with WiFi)

### Optional: Ground Pressure Reference

| Component | Adafruit Product | Price | Link |
|---|---|---|---|
| BMP390 Barometric Sensor (STEMMA QT) | PID 4816 | $12.50 | [adafruit.com/product/4816](https://www.adafruit.com/product/4816) |
| STEMMA QT Cable (100mm) | PID 4210 | $0.95 | [adafruit.com/product/4210](https://www.adafruit.com/product/4210) |

---

## Comparison

| Feature | Heltec Gateway | RP2040 Gateway |
|---|---|---|
| **Price** | ~$32 | $48-110 |
| **WiFi** | Built-in | Optional ($13) |
| **GPS** | Built-in | Optional ($40) |
| **Display** | Built-in OLED | FeatherWing OLED |
| **LoRa Chip** | SX1262 | RFM95 (SX1276) |
| **OTA Updates** | Yes | No |
| **mDNS** | Yes | No |
| **Build System** | Arduino IDE | CMake/Pico SDK |
| **Form Factor** | Compact | Modular/Stackable |
| **Expandability** | Limited | FeatherWing ecosystem |

---

## Recommendation

**For most users: Heltec Wireless Tracker**

- Lower cost ($32 vs $70+)
- All features built-in (WiFi, GPS, display)
- OTA updates - no USB needed for firmware updates
- mDNS discovery - easy to find on network
- Compact form factor

**Choose RP2040 if you:**

- Already have Feather components
- Need ground pressure reference (differential altitude)
- Want to use the Feather ecosystem for expansion
- Prefer USB serial output over WiFi

---

## Where to Buy

### Heltec
- **Heltec Official:** [heltec.org](https://heltec.org)
- **AliExpress:** Search "Heltec Wireless Tracker"
- **Amazon:** Higher price but faster shipping

### Adafruit Components
- **Adafruit:** [adafruit.com](https://www.adafruit.com)
- **DigiKey:** [digikey.com](https://www.digikey.com)
- **Mouser:** [mouser.com](https://www.mouser.com)

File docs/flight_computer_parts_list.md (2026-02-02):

# Flight Computer Parts List

Complete bill of materials for building the rocket avionics flight computer.

## Core Components

| Component | Adafruit Product | Price | Link |
|---|---|---|---|
| Feather RP2040 with RFM95 LoRa Radio (915MHz) | PID 5714 | $24.95 | [adafruit.com/product/5714](https://www.adafruit.com/product/5714) |
| BMP390 Barometric Pressure Sensor (STEMMA QT) | PID 4816 | $12.50 | [adafruit.com/product/4816](https://www.adafruit.com/product/4816) |
| LSM6DSOX + LIS3MDL 9-DoF IMU FeatherWing | PID 4565 | $19.95 | [adafruit.com/product/4565](https://www.adafruit.com/product/4565) |
| FeatherWing OLED 128x64 Display | PID 4650 | $14.95 | [adafruit.com/product/4650](https://www.adafruit.com/product/4650) |
| GPS Module (PA1010D Mini GPS) | PID 4415 | $29.95 | [adafruit.com/product/4415](https://www.adafruit.com/product/4415) |
| FeatherWing Tripler Mini Kit | PID 3417 | $8.50 | [adafruit.com/product/3417](https://www.adafruit.com/product/3417) |
| STEMMA QT Cable (100mm) | PID 4210 | $0.95 | [adafruit.com/product/4210](https://www.adafruit.com/product/4210) |
| LiPo Battery 3.7V 500mAh | PID 258 | $7.95 | [adafruit.com/product/258](https://www.adafruit.com/product/258) |

**Core Components Subtotal:** ~$120

## Pyro Channel Components

For dual parachute deployment (drogue at apogee, main at altitude).

| Component | Description | Qty | Est. Price |
|---|---|-----|---|
| IRLZ44N N-Channel MOSFET | Logic-level MOSFET for pyro firing | 2 | $2.00 |
| 1kΩ Resistor (1/4W) | MOSFET gate resistor | 2 | $0.20 |
| 10kΩ Resistor (1/4W) | Gate pull-down resistor | 2 | $0.20 |
| 2-Position Screw Terminal (5mm) | E-match connection | 2 | $1.50 |
| SPST Toggle Switch | Arm safety switch | 1 | $2.00 |
| 2N2222 NPN Transistor (optional) | Gate driver for reliable switching | 2 | $0.50 |

**Pyro Components Subtotal:** ~$7

## Optional Components

| Component | Description | Price |
|---|---|---|
| LiPo Battery 1200mAh (PID 258) | Longer flight time | $9.95 |
| FeatherWing Doubler (PID 2890) | Alternative to Tripler | $7.50 |
| uFL to SMA Adapter | External antenna option | $3.95 |
| 915MHz Antenna (SMA) | Higher gain antenna | $7.95 |

## Tools Required

- Soldering iron and solder
- Wire strippers
- Heat shrink tubing
- Multimeter (for continuity testing)
- Small Phillips screwdriver

## Assembly Overview

### Stacking Order (bottom to top)

1. **FeatherWing Tripler** - Base mounting board
2. **Feather RP2040 + RFM95** - Main MCU with LoRa radio
3. **LSM6DSOX + LIS3MDL IMU** - 9-DoF motion sensor
4. **FeatherWing OLED** - Display with buttons (on top for visibility)

### Connections

| Component | Connection | Pins |
|---|---|---|
| BMP390 | STEMMA QT (I2C) | SDA/SCL via cable |
| GPS | UART0 | GP0 (TX), GP1 (RX) |
| Pyro 1 (Drogue) | GPIO | GP24 (fire), GP26 (continuity) |
| Pyro 2 (Main) | GPIO | GP25 (fire), GP27 (continuity) |
| Arm Switch | GPIO | GP10 (active low) |
| OLED Button A | GPIO | GP9 |
| OLED Button B | GPIO | GP6 |
| OLED Button C | GPIO | GP5 |

### Pyro Channel Wiring

```
Battery (+) ──────┬──────────────────┐
                  │                  │
              [E-Match]          [E-Match]
                  │                  │
                  ├── Pyro 1 Term ───┤
                  │                  │
              [MOSFET D]         [MOSFET D]
              [IRLZ44N]          [IRLZ44N]
              [MOSFET S]         [MOSFET S]
                  │                  │
                  └────── GND ───────┘

GP24 ──[1kΩ]──┬── MOSFET Gate (Pyro 1)
              │
           [10kΩ]
              │
             GND

GP25 ──[1kΩ]──┬── MOSFET Gate (Pyro 2)
              │
           [10kΩ]
              │
             GND
```

### Continuity Detection

The continuity ADC inputs (GP26, GP27) detect whether e-matches are connected:
- Voltage divider with e-match resistance
- ADC reads ~1.5V when e-match connected
- ADC reads 0V when open circuit

## Safety Notes

1. **Never connect e-matches until ready to fly**
2. **Arm switch must be OFF during assembly and transport**
3. **Test continuity detection before each flight**
4. **Use fresh e-matches for each flight**
5. **Keep battery charged (3.7V nominal, 4.2V full)**

## Estimated Total Cost

| Category | Cost |
|---|---|
| Core Components | ~$120 |
| Pyro Components | ~$7 |
| **Total** | **~$127** |

*Prices as of January 2026. Does not include shipping or tax.*

## Where to Buy

- **Adafruit:** [adafruit.com](https://www.adafruit.com) - Primary source for Feather ecosystem
- **DigiKey:** [digikey.com](https://www.digikey.com) - MOSFETs, resistors, terminals
- **Mouser:** [mouser.com](https://www.mouser.com) - Alternative for electronic components
- **Amazon:** Backup for common components, batteries

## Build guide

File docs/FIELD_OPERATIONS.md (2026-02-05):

# Field Operations Guide

## Pre-Flight Checklist

### Equipment

- [ ] Flight computer (charged LiPo battery)
- [ ] Ground gateway (Heltec Wireless Tracker or RP2040)
- [ ] Phone/tablet with companion app
- [ ] USB cable (for emergency re-flash)
- [ ] Laptop (optional, for desktop app)

### Setup Sequence

1. **Power on gateway first** - allows it to establish WiFi AP and start listening
2. **Power on flight computer** - watch for startup sequence:
   - NeoPixel flashes during init
   - OLED shows splash screen (2 seconds)
   - OLED shows device info (2 seconds)
   - OLED shows live screen
3. **Verify sensor status** on Device Info screen:
   - Baro: BMP390 (primary) or BMP581
   - LoRa: OK
   - IMU: OK
   - GPS: OK (may take 30+ seconds for first fix)
4. **Connect app to gateway** via WiFi (`RocketGateway` AP or local network)
5. **Verify telemetry** - confirm data appears in app at 0.5 Hz
6. **Check GPS fix** - wait for satellite count > 3 on GPS screen

### Rocket ID

If flying multiple rockets:
1. Navigate to Rocket ID screen (Button C to cycle)
2. Press Button B to cycle through IDs (0-15)
3. ID is saved to flash automatically
4. Verify correct ID appears in telemetry

## Arming Procedure

1. **Verify IDLE state** on OLED display
2. **Send arm command** from app or gateway CLI:
   ```
   {"cmd":"arm","rocket":0}
   ```
3. **Confirm ARMED state:**
   - OLED shows "ARMED" with ground pressure
   - NeoPixel blinks yellow at 2 Hz
   - Telemetry rate increases to 2 Hz
4. **Ground reference is set** - do not move rocket after arming

### Important Notes
- Ground pressure reference is captured at arm time
- The complementary filter's accelerometer bias (learned during idle) is preserved
- Altitude and velocity counters are zeroed
- Arm only works from IDLE or COMPLETE states
- Disarm only works from ARMED state (cannot disarm during flight)

## Launch Detection

Launch is automatically detected when either:
- Barometric altitude exceeds 10 meters AGL, OR
- Vertical velocity exceeds 10 m/s

Upon detection:
- State transitions to BOOST
- NeoPixel blinks red at 10 Hz
- Telemetry increases to 10 Hz
- Flash recording starts (GPS launch coordinates saved)
- Mission timer begins

## During Flight

No operator action required. The state machine handles all transitions:

```
BOOST -> COAST -> APOGEE -> DESCENT -> LANDED
```

Telemetry streams at 10 Hz with full sensor data (baro, IMU, GPS).

## Post-Flight

### Recovery

1. **Check last known GPS coordinates** in app
2. **NeoPixel blinks white** at 0.5 Hz (LANDED state)
3. **Telemetry beacons** at 1 Hz for tracking
4. **Retrieve rocket**

### Data Download

Flight data can be downloaded via LoRa:

1. **List stored flights:**
   ```
   {"cmd":"flash_list"}
   ```
2. **Download flight header:**
   ```
   {"cmd":"flash_read","slot":0,"start":4294967295}
   ```
3. **Download flight samples:**
   ```
   {"cmd":"flash_read","slot":0,"start":0}
   ```
   Samples are sent 3 per packet. Request successive chunks by incrementing start index.

### Reset for Next Flight

1. **Send reset command:**
   ```
   {"cmd":"reset","rocket":0}
   ```
2. **Verify IDLE state** on display
3. **Optionally delete flight data** to free storage:
   ```
   {"cmd":"flash_delete","slot":0}
   ```
   Or delete all:
   ```
   {"cmd":"flash_delete","slot":255}
   ```

## Disarming

If launch is cancelled while ARMED:

```
{"cmd":"disarm","rocket":0}
```

Returns to IDLE state. Cannot disarm during active flight.

## Orientation Testing

For pre-flight orientation verification:

1. **Enable orientation mode:**
   ```
   {"cmd":"orientation","enable":true}
   ```
2. Telemetry increases to 10 Hz in IDLE state
3. Verify IMU axes are correct (pitch, roll, heading)
4. Mode auto-disables after 30 seconds

## Troubleshooting

### No Telemetry

- Check gateway is powered and WiFi connected
- Verify LoRa frequency match (915 MHz)
- Check rocket ID matches app target
- Verify LoRa shows "OK" on device info screen

### GPS No Fix

- Ensure clear sky view (not indoors)
- Wait up to 60 seconds for cold start
- Check satellite count on GPS screen (need >= 4 for fix)
- GPS fix timeout is 3 seconds; coordinates go stale after timeout

### Sensors Not Detected

- Power cycle the flight computer
- Check I2C connections (STEMMA QT cables, FeatherWing seating)
- Verify on Device Info screen which sensors are OK

### Flash Storage Full

- Maximum 7 flights stored
- Delete old flights via `flash_delete` command
- Each flight uses one 64KB slot regardless of duration

### Gateway IP Changed

After gateway reboot, its IP may change:
```bash
ping RocketGateway.local
```
Use the new IP for OTA flashing or direct TCP connections.

## Safety Reminders

- Always arm last, just before launch
- Verify IDLE state before handling the rocket
- Disarm if launch is scrubbed
- Do not rely solely on GPS for recovery - note launch location visually
- The flight computer has no hardware arm switch in the current build; arming is software-only via LoRa command
- Pyro channels are reserved but not yet implemented

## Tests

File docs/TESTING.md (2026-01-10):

# Rocket Avionics - Testing Procedures

## Overview

This document provides step-by-step procedures for testing the rocket avionics system before flight operations.

---

## Prerequisites

### Hardware Required
- [ ] Flight Computer: Feather RP2040 + RFM95 LoRa (Product 5714)
- [ ] Ground Gateway: Feather RP2040 + RFM95 LoRa (Product 5714)
- [ ] BMP390 Barometric Sensor (Product 4816) for flight computer via STEMMA QT
- [ ] BMP390 Barometric Sensor (Product 4816) for gateway via STEMMA QT
- [ ] GPS Module (UART, 9600 baud) connected to flight computer
- [ ] Adalogger FeatherWing with SD card inserted (Product 2922)
- [ ] FeatherWing OLED 128x64 (Product 4650)
- [ ] Quad Side-By-Side FeatherWing Kit (Product 4254)
- [ ] 2x USB-C cables
- [ ] FAT32 formatted microSD card (≤32GB recommended)

### Software Required
- [ ] Firmware files built and ready:
  - `firmware_flight/build/rocket_avionics_flight.uf2`
  - `firmware_gateway/build/rocket_gateway.uf2`
- [ ] Xojo IDE (for desktop app) or built application
- [ ] Serial terminal (screen, minicom, or PuTTY)

---

## Test 1: Firmware Flashing

### 1.1 Flash Flight Computer

1. Disconnect the flight computer from USB
2. Press and hold the **BOOTSEL** button on the Feather
3. While holding BOOTSEL, connect USB cable to computer
4. Release BOOTSEL - a drive named **RPI-RP2** should appear
5. Drag `rocket_avionics_flight.uf2` to the RPI-RP2 drive
6. The drive will disappear and the device will reboot
7. **Expected**: NeoPixel LED blinks green slowly (~1 Hz) indicating IDLE state

**Pass Criteria:**
- [ ] RPI-RP2 drive appeared
- [ ] UF2 file copied successfully
- [ ] Device rebooted automatically
- [ ] NeoPixel LED blinking green

### 1.2 Flash Ground Gateway

1. Repeat the same process with the gateway Feather
2. Drag `rocket_gateway.uf2` to the RPI-RP2 drive
3. **Expected**: Device reboots and appears as USB serial device

**Pass Criteria:**
- [ ] RPI-RP2 drive appeared
- [ ] UF2 file copied successfully
- [ ] Device rebooted automatically
- [ ] USB serial port appears (check with `ls /dev/cu.usbmodem*`)

---

## Test 2: Gateway Serial Communication

### 2.1 Connect to Gateway

```bash
# Find the serial port
ls /dev/cu.usbmodem*

# Connect (replace with actual port)
screen /dev/cu.usbmodem14101 115200
```

### 2.2 Verify Gateway Output

Wait 5 seconds. You should see periodic status messages:

```json
{"type":"link","connected":false}
```

This indicates the gateway is running but hasn't received any LoRa packets yet.

### 2.3 Send Test Commands

Type the following commands and press Enter:

```json
{"cmd":"status","id":1}
```

**Expected Response:**
```json
{"type":"ack","cmd":"status","id":1,"ok":true}
```

**Pass Criteria:**
- [ ] Gateway outputs link status messages
- [ ] Command acknowledgment received
- [ ] No error messages

*Exit screen: Press `Ctrl+A` then `K`, then `Y`*

---

## Test 3: BMP390 Sensor Verification

### 3.1 OLED Display Check

With the flight computer powered on:

1. Observe the OLED display
2. **Expected Display:**
   ```
   ROCKET AVIONICS
   State: IDLE
   Alt: 0.0 m
   Vel: 0.0 m/s
   Temp: 25.3 C
   GPS: No Fix (0 sat)
   ```

### 3.2 Pressure Value Check

1. Connect to gateway serial port
2. Observe telemetry JSON output
3. **Expected Values:**
   - `pres`: ~101,000 Pa at sea level (varies with weather/elevation)
   - `gpres`: Similar to `pres` (gateway ground pressure)
   - `temp`: 15-35°C (indoor temperature)

**Warning:** If pressure reads ~85,000 Pa instead of ~101,000 Pa, the BMP390 may not be initializing correctly. Power cycle and check I2C connections.

### 3.3 Altitude Response Test

1. Note the current altitude reading
2. Raise the flight computer approximately 1 meter above the gateway
3. Wait 2-3 seconds for reading to stabilize
4. **Expected**:
   - `alt` changes slightly (absolute altitude)
   - `dalt` increases by approximately 1 meter (differential altitude)

### 3.4 Differential Altitude Test

1. Place flight computer and gateway at the same height
2. Observe `dalt` field in telemetry
3. **Expected**: `dalt` should be near 0.0 m (±0.5m)
4. Raise flight computer 2 meters above gateway
5. **Expected**: `dalt` should read approximately 2.0 m

### 3.5 Pressure Seal Test

1. Cup your hands around the BMP390 sensor (don't touch it)
2. Breathe gently toward the sensor
3. **Expected**: Altitude reading changes (warm breath = pressure change)

**Pass Criteria:**
- [ ] OLED displays current state and readings
- [ ] Pressure values are ~101,000 Pa at sea level
- [ ] Both flight and gateway BMP390 sensors working
- [ ] Differential altitude (`dalt`) responds to height changes
- [ ] Temperature reading is reasonable (15-35°C indoors)

---

## Test 4: GPS Verification

### 4.1 Indoor GPS Test (No Fix Expected)

1. Power on flight computer indoors
2. Observe OLED display
3. **Expected**: "GPS: No Fix (0 sat)" or similar
4. Check telemetry JSON: `"gps":false`, `"sat":0`

### 4.2 Outdoor GPS Test

1. Take flight computer outside with clear sky view
2. Wait 30-60 seconds for GPS cold start
3. **Expected**:
   - OLED shows satellite count increasing
   - Eventually shows "GPS: Fix (N sat)" where N >= 3
4. Check telemetry JSON:
   - `"gps":true`
   - `"sat":` 3 or higher
   - `"lat":` valid latitude (e.g., 39.938)
   - `"lon":` valid longitude (e.g., -75.271)
   - `"gspd":` ground speed in m/s
   - `"hdg":` heading in degrees

### 4.3 GPS Movement Test

1. Walk with flight computer (GPS must have fix)
2. Observe telemetry JSON
3. **Expected**:
   - `gspd` shows walking speed (~1-2 m/s)
   - `hdg` shows direction of travel
   - `lat`/`lon` update as you move

**Pass Criteria:**
- [ ] GPS shows no fix indoors (expected)
- [ ] GPS acquires fix outdoors within 60 seconds
- [ ] Satellite count is 3 or more with fix
- [ ] Coordinates are valid for your location
- [ ] Ground speed responds to movement
- [ ] Heading responds to direction change

---

## Test 5: LoRa Communication

### 5.1 Basic Link Test

**Setup:**
- Flight computer powered on (battery or USB)
- Gateway connected to computer via USB
- Serial terminal connected to gateway

**Procedure:**

1. Power on the flight computer
2. Wait for OLED to show "IDLE" state
3. Observe gateway serial output

**Expected Gateway Output:**
```json
{"type":"tel","seq":1,"t":1000,"alt":0.5,"vel":0.0,"state":"idle","rssi":-45,"snr":10}
{"type":"tel","seq":2,"t":1100,"alt":0.5,"vel":0.0,"state":"idle","rssi":-44,"snr":11}
```

**Pass Criteria:**
- [ ] Telemetry packets received at ~10 Hz
- [ ] RSSI value present (typically -30 to -90 dBm)
- [ ] SNR value present (typically 5 to 15 dB)
- [ ] Sequence numbers incrementing
- [ ] State shows "idle"

### 5.2 Arm/Disarm Test

1. In the serial terminal, send:
   ```json
   {"cmd":"arm","id":1}
   ```

2. **Expected Flight Computer Response:**
   - OLED shows "State: ARMED"
   - NeoPixel changes to yellow, blinks faster (~2 Hz)

3. **Expected Gateway Response:**
   ```json
   {"type":"ack","cmd":"arm","id":1,"ok":true}
   {"type":"tel","seq":123,"t":12300,"alt":0.5,"vel":0.0,"state":"armed",...}
   ```

4. Send disarm command:
   ```json
   {"cmd":"disarm","id":2}
   ```

5. **Expected**: Flight computer returns to IDLE state

**Pass Criteria:**
- [ ] Arm command acknowledged
- [ ] Flight computer enters ARMED state
- [ ] Telemetry shows "armed" state
- [ ] NeoPixel changes to yellow
- [ ] Disarm returns to IDLE

---

## Test 6: SD Card Logging

### 6.1 Verify SD Card Detection

1. Insert FAT32 formatted SD card into Adalogger
2. Power cycle the flight computer
3. Check OLED for SD card status indicator

### 6.2 Generate Test Data

1. Arm the flight computer
2. Wait 30 seconds
3. Disarm the flight computer

### 6.3 Verify Log Files

1. Power off the flight computer
2. Remove SD card and insert in computer
3. Navigate to `/flights/` directory
4. Open the most recent CSV file

**Expected CSV Format:**
```csv
# Rocket Flight Data
# Flight ID: abc123...
# Date: 2026-01-10T10:30:00
Time_ms,Altitude_m,Velocity_mps,Pressure_Pa,Temperature_C,State
0,0.52,0.00,101325.0,25.3,idle
10,0.53,0.01,101324.8,25.3,idle
...
```

**Pass Criteria:**
- [ ] SD card detected on boot
- [ ] Log file created in /flights/ directory
- [ ] CSV file contains valid header
- [ ] Data logged at ~100 Hz (10ms intervals)
- [ ] Values are reasonable

---

## Test 7: Range Test

### 7.1 Preparation

- Fully charged batteries in both units
- Clear line of sight test area
- Helper with the flight computer
- You at the gateway with laptop

### 8.2 Test Procedure

| Distance | Actions | Expected RSSI |
|---|---|---|
| 10m | Walk 10m away, verify telemetry | -40 to -50 dBm |
| 50m | Walk 50m away, verify telemetry | -55 to -65 dBm |
| 100m | Walk 100m away, verify telemetry | -65 to -75 dBm |
| 250m | Walk 250m away, verify telemetry | -75 to -85 dBm |
| 500m | Walk 500m away, verify telemetry | -85 to -95 dBm |

### 7.3 Link Loss Test

1. Continue walking until telemetry stops
2. Note the maximum distance achieved
3. Return toward gateway, verify link re-establishes

**Pass Criteria:**
- [ ] Reliable telemetry at 100m
- [ ] Telemetry received at 250m
- [ ] Maximum range documented
- [ ] Link re-establishes when returning

---

## Test 8: Swing Test (Simulated Flight)

### 8.1 Setup

1. Securely attach flight computer to a 2-3 meter rope/string
2. Ensure all connections are secure (use tape if needed)
3. Clear area of obstacles
4. Arm the flight computer

### 8.2 Test Procedure

1. Swing the flight computer in a vertical arc
2. Swing height: approximately 2-3 meters
3. Perform 5-10 swings
4. Observe telemetry on gateway

**Expected Behavior:**
- Altitude increases during upswing
- Velocity positive during upswing, negative during downswing
- State may transition to BOOST/COAST if thresholds exceeded

### 8.3 Verification

Check SD card log after test:
- Altitude curve should show oscillating pattern
- Velocity should oscillate between positive and negative
- Maximum altitude should match approximate swing height

**Pass Criteria:**
- [ ] Altitude tracks swing height
- [ ] Velocity shows correct direction
- [ ] State transitions occur appropriately
- [ ] No sensor glitches or dropouts

---

## Test 9: Full System Integration

### 9.1 Desktop App Test

1. Open the Rocket Avionics Desktop application
2. Select the gateway serial port from dropdown
3. Click "Connect"
4. Verify telemetry appears in the UI:
   - Altitude label updates
   - Velocity label updates
   - State label updates
   - RSSI/SNR displays
   - Chart shows altitude profile

### 9.2 Command Test via Desktop

1. Click "ARM" button
2. Confirm arm dialog
3. Verify flight computer arms
4. Click "DISARM" button
5. Verify flight computer disarms

**Pass Criteria:**
- [ ] Desktop app connects successfully
- [ ] Live telemetry displayed
- [ ] Altitude chart updates in real-time
- [ ] ARM command works
- [ ] DISARM command works
- [ ] State colors update correctly

---

## Test Results Summary

| Test | Result | Notes |
|---|---|---|
| 1.1 Flash Flight Computer | ☐ Pass ☐ Fail | |
| 1.2 Flash Ground Gateway | ☐ Pass ☐ Fail | |
| 2.1 Gateway Serial Connect | ☐ Pass ☐ Fail | |
| 2.2 Gateway Output | ☐ Pass ☐ Fail | |
| 2.3 Gateway Commands | ☐ Pass ☐ Fail | |
| 3.1 OLED Display | ☐ Pass ☐ Fail | |
| 3.2 Pressure Values | ☐ Pass ☐ Fail | Flight: ___ Pa, Gateway: ___ Pa |
| 3.3 Altitude Response | ☐ Pass ☐ Fail | |
| 3.4 Differential Altitude | ☐ Pass ☐ Fail | |
| 3.5 Pressure Seal | ☐ Pass ☐ Fail | |
| 4.1 GPS Indoor (No Fix) | ☐ Pass ☐ Fail | |
| 4.2 GPS Outdoor (Fix) | ☐ Pass ☐ Fail | Satellites: ___ |
| 4.3 GPS Movement | ☐ Pass ☐ Fail | |
| 5.1 LoRa Basic Link | ☐ Pass ☐ Fail | RSSI: ___ dBm |
| 5.2 Arm/Disarm | ☐ Pass ☐ Fail | |
| 6.1 SD Card Detection | ☐ Pass ☐ Fail | |
| 6.2 Test Data Generation | ☐ Pass ☐ Fail | |
| 6.3 Log File Verification | ☐ Pass ☐ Fail | |
| 7. Range Test | ☐ Pass ☐ Fail | Max: ___ m |
| 8. Swing Test | ☐ Pass ☐ Fail | |
| 9.1 Desktop App | ☐ Pass ☐ Fail | |
| 9.2 Desktop Commands | ☐ Pass ☐ Fail | |

**Tested By:** _______________
**Date:** _______________
**Firmware Version:** _______________

---

## Troubleshooting

### No RPI-RP2 Drive Appears
- Try a different USB cable (data cable, not charge-only)
- Try a different USB port
- Hold BOOTSEL before plugging in, not after

### No Serial Port Appears
- Check USB cable
- Verify firmware was flashed successfully
- Try `ls /dev/cu.*` to see all serial devices

### No LoRa Telemetry Received
- Verify both devices have antennas attached (if external)
- Check that both are using same frequency (915 MHz)
- Move devices closer together for initial test
- Check RSSI - if below -100 dBm, signal is too weak

### OLED Not Displaying
- Check I2C connections (SDA/SCL)
- Verify OLED address is 0x3C
- Check for I2C bus conflicts

### SD Card Not Detected
- Ensure card is FAT32 formatted
- Card must be ≤32GB for FAT32
- Try reformatting the card
- Check SPI connections

### Altitude Reading Stuck at 0
- Check BMP390 I2C connection
- Verify sensor address (0x77)
- Look for I2C errors on OLED

---

## Pre-Flight Checklist

Before any flight operation:

- [ ] Flight computer battery fully charged
- [ ] SD card inserted and formatted
- [ ] BMP390 sensors responding (both flight and gateway)
- [ ] Pressure readings ~101,000 Pa at sea level
- [ ] GPS has fix with 3+ satellites
- [ ] GPS coordinates match launch site location
- [ ] LoRa link established with gateway
- [ ] RSSI above -80 dBm at pad
- [ ] Differential altitude near 0m with devices level
- [ ] Ground station laptop charged
- [ ] Desktop app running and connected
- [ ] Arm command tested and verified
- [ ] Weather conditions acceptable
- [ ] Recovery system verified
- [ ] Range safety officer notified

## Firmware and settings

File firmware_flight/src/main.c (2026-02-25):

//----------------------------------------------
// Module: main.c
// Description: Rocket Avionics Flight Computer
//   Main application entry point
// Author: Mark Gavin
// Created: 2026-01-10
// Copyright: (c) 2025-2026 by Mark Gavin
// License: Proprietary - All Rights Reserved
//
// Hardware:
//   - Adafruit Feather RP2040 with RFM95 LoRa 915MHz
//   - BMP390 barometric sensor (STEMMA QT)
//   - LSM6DSOX + LIS3MDL 9-DoF IMU FeatherWing
//   - FeatherWing OLED 128x64
//----------------------------------------------

#include "pins.h"
#include "version.h"
#include "flight_control.h"
#include "flight_storage.h"
#include "storage.h"
#include "bmp390.h"
#include "bmp581.h"
#include "lora_radio.h"
#ifdef DISPLAY_EINK
#include "uc8151d.h"
#include "framebuffer.h"
#else
#include "ssd1306.h"
#endif
#include "status_display.h"
#include "heartbeat_led.h"
#include "imu.h"
#include "gps.h"

#include "pico/stdlib.h"
#include "pico/multicore.h"
#include "hardware/i2c.h"
#include "hardware/spi.h"
#include "hardware/gpio.h"
#include "hardware/watchdog.h"
#include "hardware/adc.h"

#include <stdio.h>
#include <string.h>

// Eliminate printf at compile time. Both USB and UART stdio are
// disabled in CMakeLists.txt, but printf still acquires internal
// mutexes and runs formatting code. This macro removes all overhead.
// snprintf/sprintf are NOT affected (used for display formatting).
#define printf(...) ((void)0)

//----------------------------------------------
// Module Constants
//----------------------------------------------
#define kMainLoopIntervalUs     1000    // 1ms main loop (1 kHz)
#define kButtonDebounceMs       50
#define kStartupDelayMs         1000
#define kSplashDisplayMs        2000

//----------------------------------------------
// Debug Configuration
// Set to 0 to disable debug output for production
// (saves power, reduces code size)
//----------------------------------------------
#define kEnableDebugOutput      0

#if kEnableDebugOutput
  #define DEBUG_PRINT(...)  printf(__VA_ARGS__)
#else
  #define DEBUG_PRINT(...)  ((void)0)
#endif

//----------------------------------------------
// Telemetry Sample Buffer
//----------------------------------------------
static TelemetrySample sSampleBuffer[kMaxSamples] ;

//----------------------------------------------
// Module State
//----------------------------------------------
static FlightController sFlightController ;
static BMP390 sBmp390 ;
static BMP581 sBmp581 ;
static LoRa_Radio sLoRaRadio ;
static Imu sImu ;

// Hardware status
static bool sI2cBusOk = false ;
static bool sBmp390Ok = false ;
static bool sBmp581Ok = false ;
static bool sLoRaOk = false ;
static bool sImuOk = false ;
static bool sDisplayOk = false ;
static bool sGpsOk = false ;
static bool sFlashOk = false ;

// Timing
static uint32_t sLastSensorReadMs = 0 ;
static uint32_t sLastImuReadMs = 0 ;
#ifndef DISPLAY_EINK
static uint32_t sLastDisplayUpdateMs = 0 ;
#endif
static uint32_t sLastLoRaRxMs = 0 ;
static uint32_t sLastLoRaTxMs = 0 ;  // Last successful telemetry TX
static uint32_t sLastFlashLogMs = 0 ;  // Last flash logging time

// Gateway signal quality (from ACK packets)
static int16_t sGatewayRssi = 0 ;
static int8_t sGatewaySnr = 0 ;
static bool sHasAckData = false ;  // Have we received any ACKs?

// Button state
static bool sButtonAPressed = false ;
static bool sButtonBPressed = false ;
static bool sButtonCPressed = false ;
static uint32_t sButtonADownMs = 0 ;
static uint32_t sButtonBDownMs = 0 ;
static uint32_t sButtonCDownMs = 0 ;

// Flight state tracking (for flash storage transitions)
static FlightState sPreviousFlightState = kFlightIdle ;
static uint32_t sCurrentFlightId = 0 ;

// Rocket ID and name (loaded from flash, can be edited via display)
static uint8_t sRocketId = 0 ;
static bool sRocketIdEditing = false ;  // True when editing rocket ID

// Baro comparison streaming
static bool sBaroCompareEnabled = false ;
static uint32_t sLastBaroCompareMs = 0 ;
static char sRocketName[kRocketNameMaxLen] = "" ;  // Custom rocket name

//----------------------------------------------
// Forward Declarations
//----------------------------------------------
static void InitializeHardware(void) ;
static void InitializeI2C(void) ;
static void InitializeSPI(void) ;
#ifndef DISPLAY_EINK
static void InitializeButtons(void) ;
#endif
static void ProcessButtons(uint32_t inCurrentMs) ;
#ifndef DISPLAY_EINK
static void UpdateDisplay(uint32_t inCurrentMs) ;
#endif
static void SendTelemetry(uint32_t inCurrentMs) ;
static void SendBaroCompare(void) ;
static void ProcessLoRaCommands(void) ;

//----------------------------------------------
// Core1 Display Data (shared between cores)
// Lock-free design using volatile flags.
// RP2040 Cortex-M0+ has no cache and no out-of-order
// execution, so volatile alone guarantees coherence.
//----------------------------------------------
#ifdef DISPLAY_EINK

typedef struct {
  // Flight state
  FlightState pState ;
  bool pOrientationMode ;
  uint8_t pRocketId ;
  char pRocketName[16] ;
  bool pRocketIdEditing ;

  // Telemetry values
  float pAltitudeM ;
  float pVelocityMps ;
  float pAccelMagnitude ;
  float pPressurePa ;
  float pTemperatureC ;

  // Pyro continuity (ADC voltage 0-3.3V)
  float pPyro1Voltage ;
  float pPyro2Voltage ;

  // GPS
  bool pGpsOk ;
  bool pGpsFix ;
  uint8_t pGpsSatellites ;
  float pGpsLatitude ;
  float pGpsLongitude ;
  float pGpsSpeedMps ;
  float pGpsHeadingDeg ;

  // LoRa
  bool pLoRaOk ;
  bool pLoRaConnected ;
  int16_t pRssi ;
  int8_t pSnr ;
  int16_t pLastRssi ;
  uint32_t pPacketsSent ;
  uint32_t pPacketsReceived ;

  // Device status
  bool pBaroOk ;
  bool pImuOk ;
  bool pGpsStatus ;
  const char * pBaroType ;

  // Flight results
  FlightResults pResults ;
  float pGroundPressurePa ;

  // Timing
  uint32_t pCurrentMs ;
  uint32_t pLastLoRaTxMs ;
  uint32_t pLastLoRaRxMs ;
} DisplaySharedData ;

// Core0 → Core1: bulk telemetry data (core0 writes, core1 reads)
// volatile ensures compiler doesn't cache across cores
static volatile DisplaySharedData sDisplayShared ;

// Core1 → Core0: debug monitoring
static volatile uint32_t sCore1Iterations = 0 ;
static volatile float sCore1Altitude = -999.0f ;  // Altitude core1 received

// Core0 → Core1: button events (individual atomic flags)
static volatile bool sBtnCycleMode = false ;
static volatile bool sBtnHome = false ;
static volatile bool sBtnEditRocket = false ;

// Core1 → Core0: current display mode (atomic word read)
static volatile DisplayMode sCore1CurrentMode = kDisplayModeLive ;

// Core1 display loop — runs independently, can block freely
static void Core1_DisplayLoop(void) ;

#endif // DISPLAY_EINK

//----------------------------------------------
// Function: main
//----------------------------------------------
int main(void)
{
  // Initialize stdio (USB serial for debug)
  stdio_init_all() ;
  sleep_ms(kStartupDelayMs) ;

  // Check if last reboot was caused by the watchdog
  bool theWatchdogReboot = watchdog_caused_reboot() ;

  printf("\n\n") ;
  printf("======================================\n") ;
  printf("  ROCKET AVIONICS FLIGHT COMPUTER\n") ;
  printf("  Version %s\n", FIRMWARE_VERSION_STRING) ;
  printf("  Build: %s %s\n", kBuildDate, kBuildTime) ;
  if (theWatchdogReboot)
    printf("  *** WATCHDOG REBOOT ***\n") ;
  printf("======================================\n\n") ;

  // Initialize all hardware
  InitializeHardware() ;

  // If watchdog caused this reboot, flash red 3 times as warning
  if (theWatchdogReboot)
  {
    for (int i = 0 ; i < 3 ; i++)
    {
      HeartbeatLED_SetColor(kLedColorRed) ;
      sleep_ms(200) ;
      HeartbeatLED_Off() ;
      sleep_ms(200) ;
    }
  }

  // Initialize flight controller
  printf("Initializing flight controller...\n") ;
  FlightControl_Init(&sFlightController, sSampleBuffer, kMaxSamples) ;
  printf("Flight controller initialized\n") ;

  // Show splash screen
  if (sDisplayOk)
  {
    StatusDisplay_ShowSplash() ;
    sleep_ms(kSplashDisplayMs) ;

    // Show device info briefly
    const char * theBaroType = sBmp390Ok ? "BMP390" :
      (sBmp581Ok ? "BMP581" : (sI2cBusOk ? "None" : "I2C FAIL")) ;
    StatusDisplay_ShowDeviceInfo(
      FIRMWARE_VERSION_STRING,
      theBaroType,
      sBmp581Ok || sBmp390Ok,
      sLoRaOk,
      sImuOk,
      sGpsOk) ;
    sleep_ms(kSplashDisplayMs) ;

    sleep_ms(kSplashDisplayMs) ;
  }

  // Print startup summary
  printf("\nStartup complete:\n") ;
  if (sBmp390Ok)
    printf("  Baro:    BMP390 (primary)\n") ;
  if (sBmp581Ok)
    printf("  Baro:    BMP581 (%s)\n", sBmp390Ok ? "secondary" : "primary") ;
  if (!sBmp390Ok && !sBmp581Ok)
    printf("  Baro:    NONE (FAIL)\n") ;
  printf("  LoRa:    %s\n", sLoRaOk ? "OK" : "FAIL") ;
  printf("  IMU:     %s\n", sImuOk ? "OK" : "FAIL") ;
  printf("  Display: %s\n", sDisplayOk ? "OK" : "FAIL") ;
  printf("  GPS:     %s\n", sGpsOk ? "OK" : "FAIL") ;
  printf("  Flash:   %s\n", sFlashOk ? "OK" : "FAIL") ;
  printf("\nEntering main loop...\n\n") ;

#ifdef DISPLAY_EINK
  // Launch core1 for eInk display updates.
  // All display I/O moves to core1 so it can block
  // on eInk refresh without affecting LoRa on core0.
  if (sDisplayOk)
  {
    memset((void *)&sDisplayShared, 0, sizeof(sDisplayShared)) ;
    sDisplayShared.pBaroType = sBmp390Ok ? "BMP390" :
      (sBmp581Ok ? "BMP581" : (sI2cBusOk ? "None" : "I2C FAIL")) ;
    sDisplayShared.pBaroOk = sBmp390Ok || sBmp581Ok ;
    sDisplayShared.pLoRaOk = sLoRaOk ;
    sDisplayShared.pImuOk = sImuOk ;
    sDisplayShared.pGpsStatus = sGpsOk ;
    printf("Launching Core1 for eInk display...\n") ;
    multicore_launch_core1(Core1_DisplayLoop) ;
    printf("Core1 launched OK\n") ;
  }
#endif

  printf("Starting main loop...\n") ;

  // Put LoRa in receive mode to listen for commands
  if (sLoRaOk)
  {
    LoRa_StartReceive(&sLoRaRadio) ;
  }

  // Hardware watchdog — temporarily disabled while debugging GPS
  // watchdog_enable(8000, true) ;

  // Main loop
  uint32_t theLastLoopUs = time_us_32() ;

  while (1)
  {
    uint32_t theCurrentMs = to_ms_since_boot(get_absolute_time()) ;

    //------------------------------------------
    // 1. Read sensors (100 Hz)
    //------------------------------------------
    if ((theCurrentMs - sLastSensorReadMs) >= kSensorSampleIntervalMs)
    {
      sLastSensorReadMs = theCurrentMs ;

      // Read barometers
      float thePressure = 0 ;
      float theTemperature = 0 ;
      bool theReadOk = false ;

      // Read BMP390 (primary when available)
      float the390Pressure = 0 ;
      float the390Temperature = 0 ;
      bool the390Ok = false ;
      if (sBmp390Ok)
      {
        the390Ok = BMP390_ReadPressureTemperature(&sBmp390, &the390Pressure, &the390Temperature) ;
      }

      // Read BMP581
      float the581Pressure = 0 ;
      float the581Temperature = 0 ;
      bool the581Ok = false ;
      if (sBmp581Ok)
      {
        the581Ok = BMP581_ReadPressureTemperature(&sBmp581, &the581Pressure, &the581Temperature) ;
      }

      // Use BMP390 as primary if available, else BMP581
      if (the390Ok)
      {
        thePressure = the390Pressure ;
        theTemperature = the390Temperature ;
        theReadOk = true ;
      }
      else if (the581Ok)
      {
        thePressure = the581Pressure ;
        theTemperature = the581Temperature ;
        theReadOk = true ;
      }

      if (theReadOk)
      {
        FlightControl_UpdateSensors(
          &sFlightController,
          thePressure,
          theTemperature,
          theCurrentMs) ;
      }

      // Update GPS (reads UART and parses NMEA sentences)
      if (sGpsOk)
      {
        GPS_Update(theCurrentMs) ;
      }
    }


    //------------------------------------------
    // 2. Read IMU (100 Hz)
    //------------------------------------------
    if (sImuOk && (theCurrentMs - sLastImuReadMs) >= kImuSampleIntervalMs)
    {
      sLastImuReadMs = theCurrentMs ;

      // Only feed complementary filter when IMU read succeeds.
      // On I2C failure, skip update to avoid stale data corruption.
      if (IMU_Read(&sImu))
      {
        FlightControl_UpdateImu(&sFlightController, &sImu.pData, theCurrentMs) ;
      }
    }



    //------------------------------------------
    // 3. Update flight state machine
    //------------------------------------------
    FlightControl_Update(&sFlightController, theCurrentMs) ;

    // Check for orientation mode timeout (30 seconds)
    FlightControl_CheckOrientationTimeout(&sFlightController, theCurrentMs, 30000) ;

    //------------------------------------------
    // 3a. Handle flight state transitions for flash storage
    //------------------------------------------
    FlightState theCurrentState = FlightControl_GetState(&sFlightController) ;
    if (theCurrentState != sPreviousFlightState)
    {
      // Log all state transitions
      char theBuf[48] ;
      snprintf(theBuf, sizeof(theBuf), "MAIN STATE: %s -> %s",
        FlightControl_GetStateName(sPreviousFlightState),
        FlightControl_GetStateName(theCurrentState)) ;
      puts(theBuf) ;
    }
    if (sFlashOk && theCurrentState != sPreviousFlightState)
    {
      // State changed - check for recording start/stop
      if (theCurrentState == kFlightBoost && sPreviousFlightState == kFlightArmed)
      {
        // Launch detected - start recording
        const GpsData * theGps = sGpsOk ? GPS_GetData() : NULL ;
        int32_t theLaunchLat = (theGps && theGps->pValid) ?
          (int32_t)(theGps->pLatitude * 1000000.0f) : 0 ;
        int32_t theLaunchLon = (theGps && theGps->pValid) ?
          (int32_t)(theGps->pLongitude * 1000000.0f) : 0 ;

        sCurrentFlightId = FlightStorage_StartFlight(
          sFlightController.pGroundPressurePa,
          theLaunchLat,
          theLaunchLon) ;

        if (sCurrentFlightId > 0)
        {
          DEBUG_PRINT("Flash: Started recording flight %lu\n", (unsigned long)sCurrentFlightId) ;
          sLastFlashLogMs = theCurrentMs ;
        }
        else
        {
          DEBUG_PRINT("Flash: Failed to start recording (storage full?)\n") ;
        }
      }
      else if (theCurrentState == kFlightLanded && sPreviousFlightState == kFlightDescent)
      {
        // Landing detected - end recording
        if (FlightStorage_IsRecording())
        {
          bool theSaved = FlightStorage_EndFlight(
            sFlightController.pResults.pMaxAltitudeM,
            sFlightController.pResults.pMaxVelocityMps,
            sFlightController.pResults.pApogeeTimeMs,
            sFlightController.pResults.pFlightTimeMs) ;

          if (theSaved)
          {
            DEBUG_PRINT("Flash: Flight %lu saved (%lu samples)\n",
              (unsigned long)sCurrentFlightId,
              (unsigned long)sFlightController.pSampleCount) ;
          }
          else
          {
            DEBUG_PRINT("Flash: Failed to save flight %lu\n", (unsigned long)sCurrentFlightId) ;
          }
          sCurrentFlightId = 0 ;
        }
      }

      sPreviousFlightState = theCurrentState ;
    }

    // Auto-recover from spurious flight detection.
    // If state reached LANDED/COMPLETE but max altitude < 20m,
    // no real flight occurred — reset to IDLE.
    // Threshold above launch detection (10m) so phantom flights are caught.
    if ((theCurrentState == kFlightLanded || theCurrentState == kFlightComplete) &&
        sFlightController.pResults.pMaxAltitudeM < 20.0f)
    {
      puts("*** AUTO-RESET: spurious flight (maxAlt < 20m) ***") ;
      FlightControl_Reset(&sFlightController) ;
      sPreviousFlightState = kFlightIdle ;
    }

    //------------------------------------------
    // 3b. Log samples to flash (10 Hz during flight)
    //------------------------------------------
    if (sFlashOk && FlightStorage_IsRecording() &&
        (theCurrentMs - sLastFlashLogMs) >= kTelemetryIntervalMs)
    {
      sLastFlashLogMs = theCurrentMs ;

      // Build sample from current sensor data
      FlightSample theSample ;
      theSample.pTimeMs = theCurrentMs - sFlightController.pLaunchTimeMs ;
      theSample.pAltitudeCm = (int32_t)(sFlightController.pCurrentAltitudeM * 100.0f) ;
      theSample.pVelocityCmps = (int16_t)(sFlightController.pCurrentVelocityMps * 100.0f) ;
      theSample.pPressurePa = (uint32_t)sFlightController.pCurrentPressurePa ;
      theSample.pTemperatureC10 = (int16_t)(sFlightController.pCurrentTemperatureC * 10.0f) ;

      // GPS data
      const GpsData * theGps = sGpsOk ? GPS_GetData() : NULL ;
      if (theGps != NULL && theGps->pValid)
      {
        theSample.pGpsLatitude = (int32_t)(theGps->pLatitude * 1000000.0f) ;
        theSample.pGpsLongitude = (int32_t)(theGps->pLongitude * 1000000.0f) ;
        theSample.pGpsSpeedCmps = (int16_t)(theGps->pSpeedMps * 100.0f) ;
        theSample.pGpsHeadingDeg10 = (uint16_t)(theGps->pHeadingDeg * 10.0f) ;
        theSample.pGpsSatellites = theGps->pSatellites ;
      }
      else
      {
        theSample.pGpsLatitude = 0 ;
        theSample.pGpsLongitude = 0 ;
        theSample.pGpsSpeedCmps = 0 ;
        theSample.pGpsHeadingDeg10 = 0 ;
        theSample.pGpsSatellites = 0 ;
      }

      // IMU data
      const ImuData * theImuData = sImuOk ? IMU_GetData(&sImu) : NULL ;
      if (theImuData != NULL)
      {
        // Accelerometer: convert from g to milli-g
        theSample.pAccelX = (int16_t)(theImuData->pAccelX * 1000.0f) ;
        theSample.pAccelY = (int16_t)(theImuData->pAccelY * 1000.0f) ;
        theSample.pAccelZ = (int16_t)(theImuData->pAccelZ * 1000.0f) ;

        // Gyroscope: convert from dps to 0.1 dps
        theSample.pGyroX = (int16_t)(theImuData->pGyroX * 10.0f) ;
        theSample.pGyroY = (int16_t)(theImuData->pGyroY * 10.0f) ;
        theSample.pGyroZ = (int16_t)(theImuData->pGyroZ * 10.0f) ;

        // Magnetometer: convert from gauss to milligauss
        theSample.pMagX = (int16_t)(theImuData->pMagX * 1000.0f) ;
        theSample.pMagY = (int16_t)(theImuData->pMagY * 1000.0f) ;
        theSample.pMagZ = (int16_t)(theImuData->pMagZ * 1000.0f) ;
      }
      else
      {
        theSample.pAccelX = 0 ;
        theSample.pAccelY = 0 ;
        theSample.pAccelZ = 0 ;
        theSample.pGyroX = 0 ;
        theSample.pGyroY = 0 ;
        theSample.pGyroZ = 0 ;
        theSample.pMagX = 0 ;
        theSample.pMagY = 0 ;
        theSample.pMagZ = 0 ;
      }

      theSample.pState = (uint8_t)theCurrentState ;

      FlightStorage_LogSample(&theSample) ;
    }


    //------------------------------------------
    // 4. Send LoRa telemetry (10 Hz) — PRIORITY
    //------------------------------------------
    if (sLoRaOk && FlightControl_ShouldSendTelemetry(&sFlightController, theCurrentMs))
    {
      SendTelemetry(theCurrentMs) ;
    }

    //------------------------------------------
    // 5. Send baro comparison (1 Hz when enabled)
    //------------------------------------------
    if (sLoRaOk && sBaroCompareEnabled && sBmp390Ok && sBmp581Ok &&
        (theCurrentMs - sLastBaroCompareMs) >= 1000)
    {
      sLastBaroCompareMs = theCurrentMs ;
      SendBaroCompare() ;
    }

    //------------------------------------------
    // 6. Process incoming LoRa commands
    //------------------------------------------
    if (sLoRaOk)
    {
      ProcessLoRaCommands() ;
    }

    //------------------------------------------
    // 7. Update display
    //------------------------------------------
#ifdef DISPLAY_EINK
    // eInk: populate shared data for core1 (lock-free)
    // Core0 writes unconditionally; core1 reads when ready.
    // Torn reads are harmless for display purposes.
    if (sDisplayOk)
    {
      const GpsData * theGps = sGpsOk ? GPS_GetData() : NULL ;

      sDisplayShared.pState = FlightControl_GetState(&sFlightController) ;
      sDisplayShared.pOrientationMode = sFlightController.pOrientationMode ;
      sDisplayShared.pRocketId = sRocketId ;
      memcpy((void *)sDisplayShared.pRocketName, sRocketName, sizeof(sDisplayShared.pRocketName) - 1) ;
      sDisplayShared.pRocketIdEditing = sRocketIdEditing ;

      sDisplayShared.pAltitudeM = sFlightController.pCurrentAltitudeM ;
      sDisplayShared.pVelocityMps = sFlightController.pCurrentVelocityMps ;
      sDisplayShared.pPressurePa = sFlightController.pCurrentPressurePa ;
      sDisplayShared.pTemperatureC = sFlightController.pCurrentTemperatureC ;
      sDisplayShared.pGroundPressurePa = sFlightController.pGroundPressurePa ;
      sDisplayShared.pResults = sFlightController.pResults ;

      // IMU acceleration magnitude
      const ImuData * theImuForDisplay = sImuOk ? IMU_GetData(&sImu) : NULL ;
      sDisplayShared.pAccelMagnitude = theImuForDisplay ? theImuForDisplay->pAccelMagnitude : 0.0f ;

      // Pyro continuity ADC (GP26=ADC0, GP27=ADC1)
      adc_select_input(0) ;
      sDisplayShared.pPyro1Voltage = adc_read() * 3.3f / 4095.0f ;
      adc_select_input(1) ;
      sDisplayShared.pPyro2Voltage = adc_read() * 3.3f / 4095.0f ;

      sDisplayShared.pGpsOk = sGpsOk ;
      sDisplayShared.pGpsFix = (theGps != NULL) && theGps->pValid ;
      sDisplayShared.pGpsSatellites = (theGps != NULL) ? theGps->pSatellites : 0 ;
      sDisplayShared.pGpsLatitude = (theGps != NULL) ? theGps->pLatitude : 0.0f ;
      sDisplayShared.pGpsLongitude = (theGps != NULL) ? theGps->pLongitude : 0.0f ;
      sDisplayShared.pGpsSpeedMps = (theGps != NULL) ? theGps->pSpeedMps : 0.0f ;
      sDisplayShared.pGpsHeadingDeg = (theGps != NULL) ? theGps->pHeadingDeg : 0.0f ;

      sDisplayShared.pLoRaOk = sLoRaOk ;
      sDisplayShared.pLoRaConnected = sLoRaOk && (sLastLoRaRxMs > 0) &&
        ((theCurrentMs - sLastLoRaRxMs) < kLoRaTimeoutMs) ;
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

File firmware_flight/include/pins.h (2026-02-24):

//----------------------------------------------
// Module: pins.h
// Description: GPIO pin assignments for Rocket
//   Avionics Flight Computer
// Author: Mark Gavin
// Created: 2026-01-10
// Copyright: (c) 2025-2026 by Mark Gavin
// License: Proprietary - All Rights Reserved
//
// Hardware:
//   - Adafruit Feather RP2040 with RFM95 LoRa 915MHz (5714)
//   - Adafruit BMP390 Barometric Sensor (4816)
//   - Adafruit LSM6DSOX + LIS3MDL FeatherWing 9-DoF IMU (4565)
//   - Adafruit FeatherWing OLED 128x64 (SSD1306) (4650)
//   - Quad Side-By-Side FeatherWing Kit (4254)
//
// Note: The Feather RP2040 RFM95 uses SPI1 (not SPI0!)
//       with different pins than generic Feather RP2040
//----------------------------------------------

#pragma once

#include "hardware/i2c.h"
#include "hardware/spi.h"

//----------------------------------------------
// I2C Bus (STEMMA QT + FeatherWing bus)
// Shared by: BMP390, PCF8523 RTC, SSD1306 OLED
//----------------------------------------------
#define kPinI2cSda          2   // GP2 - I2C SDA (Feather default)
#define kPinI2cScl          3   // GP3 - I2C SCL (Feather default)
#define kI2cPort            i2c1  // Feather uses I2C1 on these pins
#define kI2cBaudrate        400000  // 400 kHz

//----------------------------------------------
// I2C Device Addresses
//----------------------------------------------
#define kI2cAddrBMP390      0x77  // Barometric sensor (or 0x76 if SDO to GND)
#define kI2cAddrSSD1306     0x3C  // OLED display (or 0x3D)
#define kI2cAddrLSM6DSOX    0x6A  // IMU accel/gyro (or 0x6B if SDO to VDD)
#define kI2cAddrICM20649    0x68  // ICM-20649 accel/gyro (or 0x69 if AD0 HIGH)
#define kI2cAddrLIS3MDL     0x1E  // IMU magnetometer (or 0x1C if SDO to GND)

//----------------------------------------------
// SPI1 - LoRa Radio
// Feather RP2040 RFM95 uses SPI1 on pins 8, 14, 15
// See: https://learn.adafruit.com/feather-rp2040-rfm95/pinouts
//----------------------------------------------
#define kPinSpiSck          14  // GP14 - SPI1 SCK
#define kPinSpiMosi         15  // GP15 - SPI1 TX/MOSI
#define kPinSpiMiso         8   // GP8 - SPI1 RX/MISO
#define kSpiPort            spi1
#define kSpiLoRaBaudrate    1000000   // 1 MHz for LoRa

//----------------------------------------------
// LoRa Radio (RFM95 built into Feather RP2040 RFM95)
//----------------------------------------------
#define kPinLoRaCs          16  // GP16 - RFM95 Chip Select
#define kPinLoRaReset       17  // GP17 - RFM95 Reset
#define kPinLoRaDio0        21  // GP21 - RFM95 DIO0 (RX Done interrupt)
#define kPinLoRaDio1        22  // GP22 - RFM95 DIO1 (optional)

//----------------------------------------------
// OLED FeatherWing Buttons
// Active LOW (internal pull-up, grounded when pressed)
//----------------------------------------------
#define kPinButtonA         9   // GP9 - Button A (left) - D9
#define kPinButtonB         6   // GP6 - Button B (middle) - D6
#define kPinButtonC         5   // GP5 - Button C (right) - D5

//----------------------------------------------
// Status LED (Built-in NeoPixel)
//----------------------------------------------
#define kPinNeoPixel        4   // GP4 - Built-in NeoPixel

//----------------------------------------------
// GPS (Adafruit Ultimate GPS)
// Supported modules:
//   - Ultimate GPS FeatherWing (PID 3133) - PA1616D / MT3339
//   - Ultimate GPS Breakout (PID 5440) - PA1616D / MTK3333
// Uses UART0. RX on GP13 (D13) instead of GP1 to avoid
// crosstalk into adjacent I2C lines (GP2/GP3).
// MTK3333 outputs $GN prefix (multi-GNSS); parser handles both $GP and $GN
//----------------------------------------------
#define kPinGpsTx           0   // GP0 - UART0 TX (to GPS RX)
#define kPinGpsRx           1   // GP1 - UART0 RX (from GPS TX)
#define kGpsUartPort        uart0
#define kGpsUartBaudrate    9600  // GPS default baud rate
// Note: FeatherWing has EN wired always-on. Breakout has EN pin with
// internal pull-up (HIGH = enabled). Leave unconnected or drive HIGH.
// If using carrier board with GPIO-controlled enable, uncomment:
// #define kPinGpsEnable    11  // Optional GPS enable pin (active high)

//----------------------------------------------
// Future: Pyro Channels (for ejection charges)
// Note: GP24/GP25 reassigned to eInk display SPI.
// Pyro pins will be assigned on carrier board revision.
//----------------------------------------------
#define kPinPyro1Continuity 26  // GP26/A0 - Drogue continuity ADC (future)
#define kPinPyro2Continuity 27  // GP27/A1 - Main continuity ADC (future)

//----------------------------------------------
// Multi-Rocket Configuration
//----------------------------------------------
#define kRocketId           0           // Unique rocket ID (0-15)
                                        // Change this for each flight computer!
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

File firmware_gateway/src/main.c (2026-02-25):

//----------------------------------------------
// Module: main.c
// Description: Rocket Avionics Ground Gateway
//   LoRa to USB serial bridge
// Author: Mark Gavin
// Created: 2026-01-10
// Modified: 2026-01-13 (Switched to OLED display)
// Copyright: (c) 2025-2026 by Mark Gavin
// License: Proprietary - All Rights Reserved
//
// Hardware:
//   - Adafruit Feather RP2040 with RFM95 LoRa 915MHz
//   - Adafruit FeatherWing OLED 128x64 (4650)
//   - Adafruit BMP390 Barometric Sensor (4816)
//----------------------------------------------

#include "pins.h"
#include "version.h"
#include "lora_radio.h"
#include "gateway_protocol.h"
#include "gateway_display.h"
#include "bmp390.h"
#include "bmp581.h"
#include "neopixel.h"
#if kEnableGps
#include "gps.h"
#endif
#if kEnableWifi
#include "wifi_nina.h"
#include "wifi_config.h"
#endif

#include "pico/stdlib.h"
#include "pico/stdio_usb.h"
#include "hardware/spi.h"
#include "hardware/gpio.h"
#include "hardware/i2c.h"

#include <stdio.h>
#include <string.h>

//----------------------------------------------
// Module Constants
//----------------------------------------------
#define kMainLoopIntervalMs     1
#define kLedBlinkFastMs         250
#define kLedBlinkSlowMs         1000
#define kLinkTimeoutMs          5000
#define kUsbLineBufferSize      256
#define kStartupDelayMs         1000
#define kOledUpdateIntervalMs   200   // 5 Hz display update
#define kBmp390ReadIntervalMs   100   // 10 Hz sensor reading
#define kSplashDurationMs       1500  // Splash screen duration
#define kGpsUpdateIntervalMs    100   // 10 Hz GPS update

//----------------------------------------------
// Debug Configuration
// Set to 0 to disable debug output that can
// interfere with protocol JSON parsing
//----------------------------------------------
#define kEnableDebugOutput      0

#if kEnableDebugOutput
  #define DEBUG_PRINT(...)  printf(__VA_ARGS__)
#else
  #define DEBUG_PRINT(...)  ((void)0)
#endif

//----------------------------------------------
// Output Helper (USB + optional WiFi)
//----------------------------------------------
#if kEnableWifi
  // Forward declaration - implemented at end of file
  static void OutputToAll(const char * inJson) ;
  #define OUTPUT_JSON(json) OutputToAll(json)
#else
  #define OUTPUT_JSON(json) do { printf("%s", json); stdio_flush(); } while(0)
#endif

//----------------------------------------------
// Module State
//----------------------------------------------
static LoRa_Radio sLoRaRadio ;
static GatewayState sGatewayState ;
static BMP390 sBmp390 ;
static BMP581 sBmp581 ;
static bool sLoRaOk = false ;
static bool sDisplayOk = false ;
static bool sUsbConnected = false ;
static bool sBmp390Ok = false ;
static bool sBmp581Ok = false ;
static bool sGpsOk = false ;

// Ground barometer data
static float sGroundPressurePa = 0.0f ;
static float sGroundTemperatureC = 0.0f ;

// LED timing
static uint32_t sLastLedToggleMs = 0 ;
static bool sLedState = false ;

// Display timing
static uint32_t sLastDisplayUpdateMs = 0 ;
static uint32_t sLastUsbCheckMs = 0 ;
static uint32_t sLastBmp390ReadMs = 0 ;
static uint32_t sLastGpsUpdateMs = 0 ;

// Button state
static bool sButtonAState = false ;
static bool sButtonBState = false ;
static bool sButtonCState = false ;
static uint32_t sButtonALastMs = 0 ;
static uint32_t sButtonBLastMs = 0 ;
static uint32_t sButtonCLastMs = 0 ;

// USB input buffer
static char sUsbLineBuffer[kUsbLineBufferSize] ;
static int sUsbLinePos = 0 ;

// WiFi state (conditional)
#if kEnableWifi
static bool sWifiOk = false ;
static WifiMode_t sWifiMode = kWifiModeNone ;
static int8_t sWifiServerSocket = -1 ;
static int8_t sWifiClientSocket = -1 ;
static bool sWifiClientConnected = false ;
static char sWifiLineBuffer[kUsbLineBufferSize] ;
static int sWifiLinePos = 0 ;
#endif

//----------------------------------------------
// Forward Declarations
//----------------------------------------------
static void InitializeHardware(void) ;
static void InitializeI2C(void) ;
static void InitializeSPI(void) ;
static void InitializeButtons(void) ;
static void ProcessLoRaPackets(uint32_t inCurrentMs) ;
static void ProcessUsbInput(uint32_t inCurrentMs) ;
static void ProcessButtons(uint32_t inCurrentMs) ;
static void UpdateLed(uint32_t inCurrentMs) ;
static void UpdateDisplay(uint32_t inCurrentMs) ;
static void ReadGroundBarometer(uint32_t inCurrentMs) ;
#if kEnableWifi
static void ProcessWifiInput(uint32_t inCurrentMs) ;
static void ProcessCommandLine(const char * inLine, bool inIsWifi) ;
static void OutputToAll(const char * inJson) ;
#endif
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

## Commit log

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2026-01-10 Fix PopupMenu API and replace timer with refresh button
    - Change SelectedRowText to Text (correct Xojo PopupMenu API)
    - Remove TimerRefreshPorts auto-refresh timer
    - Add manual refresh button next to port dropdown
    - Simplify RefreshSerialPorts method
2026-01-10 Fix: Send heartbeat telemetry in IDLE state
    Previously the flight computer only transmitted telemetry when armed
    or during flight. Now sends heartbeat at 0.5 Hz (every 2 seconds)
    in IDLE state to allow link verification before arming.
    Telemetry rates:
    - IDLE/LANDED/COMPLETE: 0.5 Hz (heartbeat)
    - ARMED: 1 Hz (ready for launch)
    - BOOST through DESCENT: 10 Hz (full rate)
2026-01-10 Fix: Telemetry timestamp not being updated (caused 1000Hz spam)
    The flight controller's pLastTelemetryTimeMs was never updated after
    sending telemetry, causing FlightControl_ShouldSendTelemetry() to always
    return true. This resulted in telemetry being sent every loop iteration
    (~1000 Hz) instead of the intended rate, corrupting LoRa transmissions.
    Changes:
    - Add FlightControl_MarkTelemetrySent() to update timestamp and sequence
    - Switch to LoRa_SendBlocking() to ensure packets complete
    - Return to receive mode after sending
    - Remove unused sLastTelemetryMs variable
    [main.c]
2026-01-10 Fix BMP390 sensor readings stuck/not updating
    - Change from normal mode to forced mode measurement
    - Explicitly trigger measurement before each read
    - Wait for data-ready status flag before reading values
    - Add raw ADC debug output (every 100th reading)
    - Add BMP390 driver to gateway for ground pressure reference
    Normal mode was not reliably producing new measurements, causing
    readings to be stuck at incorrect values (~85000 Pa instead of
    ~101000 Pa at sea level).
    [bmp390.c]
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2026-01-10 Update flight status display for GPS data
    - Add GPS status and satellite count to OLED display
    - Show coordinates when GPS has fix
    - Update display layout for new telemetry fields
    [status_display.c]
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2026-01-13 Replace Adalogger with LSM6DSOX+LIS3MDL 9-DoF IMU FeatherWing
    Hardware changes:
    - Remove Adalogger FeatherWing (SD card + RTC) from flight computer
    - Add LSM6DSOX + LIS3MDL 9-DoF IMU FeatherWing (Product 4565)
    - Data logging continues via flash storage
    New IMU driver (imu.h/imu.c):
    - LSM6DSOX accelerometer/gyroscope driver (I2C 0x6A)
    - LIS3MDL magnetometer driver (I2C 0x1C/0x1E auto-detect)
    - Orientation calculation (pitch, roll, tilt-compensated heading)
    - Configured for rocket mounting: Y=vertical, X=right, Z=toward observer
    New display screens:
    - IMU: Artificial horizon with pitch/roll, acceleration bar, gyro rates
    - Spin: Spin rate gauge showing rotation around vertical axis (±500°/s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
    [imu.c, main.c, pins.h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]
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2026-01-14 Add device info screen to gateway and conditional GPS compilation
    Gateway display:
    - Add kGwDisplayModeDeviceInfo to display mode enum (before About)
    - Add GatewayDisplay_ShowDeviceInfo() with cached hardware status
    - Show device info screen at startup after splash
    - Device info accessible via button cycling through display modes
    Conditional GPS:
    - Add kEnableGps compile-time flag to pins.h (default 0 for no GPS)
    - Wrap all GPS code with #if kEnableGps conditionals
    - Device info correctly shows GPS: FAIL when disabled
    Flight computer:
    - Move kDisplayModeDeviceInfo to position 9 (just before About)
    [main.c, pins.h]
2026-01-15 Add Heltec Wireless Tracker gateway firmware with WiFi fallback mode
    Replace AirLift FeatherWing (NINA SPI protocol issues) with Heltec
    Wireless Tracker which has native ESP32-S3 WiFi, SX1262 LoRa, and GPS.
    - LoRa RX/TX matching flight computer (915MHz, SF7, 125kHz, sync 0x14)
    - WiFi fallback: tries station mode first, falls back to AP mode
    - TCP server on port 5000 for telemetry forwarding
    - GPS reading with TinyGPS++
    - LCD status display showing mode, IP, packet count, GPS fix
    - Bidirectional forwarding (LoRa<->WiFi)
    Disabled WiFi in original RP2040 firmware (kEnableWifi=0) as backup.
    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
    [firmware_gateway_heltec.ino, pins.h]
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2026-01-17 Add per-component versioning with force-rebuilt build timestamps
    - Add version.c with kBuildDate/kBuildTime for gateway and flight firmware
    - CMake touches version.c before each build to ensure fresh timestamps
    - Update main.c files to use kBuildDate/kBuildTime instead of __DATE__/__TIME__
    - Add version.h to Heltec gateway with FIRMWARE_VERSION_STRING
    Build timestamps now update correctly on every build regardless of
    which source files changed.
    [firmware_gateway_heltec.ino, main.c]
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2026-01-28 Heltec Gateway v1.2.0: Binary telemetry decoding and WiFi station mode
    - Add binary-to-JSON telemetry decoding for flight computer packets
    - Fix packet truncation caused by String class with null bytes
    - Add LoRaTelemetryPacket struct matching flight computer format
    - Decode all fields: altitude, velocity, GPS, IMU (accel/gyro/mag), state
    - Include RSSI/SNR in JSON output for signal quality monitoring
    - Configure WiFi station mode for AppligentGuestAirport network
    - Forward unknown packets as hex for debugging
    - Update display to show packet size instead of truncated content
    [firmware_gateway_heltec.ino]
2026-01-28 Heltec Gateway v1.3.0: Full command protocol implementation
    Gateway-local commands:
    - gw_info: Fixed response format to match desktop app fields
    - status: Added gateway status with rx/tx counts, rssi/snr, uptime
    - ping: Added ping response with ack
    JSON to binary command translation for flight computer:
    - arm, disarm, reset commands
    - fc_info request
    - orientation_mode enable/disable
    - flash_list, flash_read, flash_delete commands
    Binary to JSON response translation from flight computer:
    - fc_info (device info) response decoding
    - flash_list (storage list) response decoding
    - flash_data/flash_header response forwarding
    - ack packet forwarding
    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
    [firmware_gateway_heltec.ino]
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2026-01-28 Heltec Gateway v1.4.0: Add runtime-adjustable gateway settings
    Add ability to change gateway power settings from desktop app to reduce heat:
    - Display backlight (0-255)
    - LoRa TX power (2-20 dBm)
    - WiFi TX power (0-20 dBm)
    Gateway firmware:
    - Add gw_get_settings command to query current values and ranges
    - Add gw_set command to apply settings immediately
    - Runtime variables track current settings (reset on restart)
    Desktop app:
    - Add Gateway Settings dialog with sliders (View > Gateway Settings, Cmd+Shift+G)
    - Add GatewaySettingsReceived event to FlightConnection
    - Add SendGetGatewaySettings/SendGatewaySettings methods
    [firmware_gateway_heltec.ino]
2026-01-28 Heltec Gateway v1.4.1: Add battery voltage monitoring
    Add LiPo battery monitoring for Heltec Wireless Tracker:
    - Read battery voltage via GPIO37 ADC with voltage divider
    - Display voltage and percentage on TFT (bottom right, color-coded)
    - Include battery_v and battery_pct in status and gw_info responses
    - Green (>3.8V), Yellow (3.5-3.8V), Red (<3.5V) color indicators
    - Averaged sampling (10 samples) for stability
    - Updates every 2 seconds
    [firmware_gateway_heltec.ino]
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2026-01-28 Revert battery monitoring - ADC pin undocumented
    The Heltec Wireless Tracker battery voltage ADC pin is not documented
    and readings were unstable across GPIO 1-10. Disabling battery
    monitoring until the correct pin can be identified.
    Reverts version to 1.4.0 (gateway settings feature).
    [firmware_gateway_heltec.ino]
2026-01-29 Heltec Gateway v1.5.0: Add distance to rocket display
    Calculate and display distance from gateway to rocket using GPS:
    - Haversine formula for great-circle distance
    - Display on TFT Row 4: "Dist: 1.23 km" or "Dist: 456 m"
    - Include "dist" field in telemetry JSON forwarded to apps
    - Requires both gateway GPS fix and rocket GPS in telemetry
    [firmware_gateway_heltec.ino]
2026-01-29 iOS: Fix recovery compass to rotate with phone orientation
    The compass arrow now points in the direction you need to WALK:
    - Added iPhone compass/heading support to Module_Location
    - Calculate relative bearing (absolute bearing - phone heading)
    - Arrow rotates as you turn the phone
    - Gray arrow with "no compass" shown if heading unavailable
    - Absolute bearing still displayed in center as reference
    This makes the recovery screen actually useful for navigation.
2026-01-30 iOS: Rebuild app with fixed AutoLayout and working screens
    - Rewrote all screens with correct AutoLayout format to fix stack overflow crash
    - Screen_Main: Telemetry display with altitude, velocity, state, RSSI/SNR
    - Screen_Settings: Gateway connection with host/port fields
    - Screen_Recovery: Navigation with distance, bearing, coordinates, Open in Maps
    - Screen_FlashStorage: Flight data listing with refresh from rocket
    - FlightConnection: Rewritten with proper TCPSocket event handlers
    - Removed AltitudeChartView (was causing crashes)
    - Added proper AddHandler/RemoveHandler patterns for connection events
2026-01-30 Flight: Add rocket ID display and editing via display button
    - Add kDisplayModeRocketId screen to view/edit rocket ID (0-15)
    - Button B cycles through rocket IDs when on the ID screen
    - Rocket ID saved to flash and persists across power cycles
    - Display rocket ID in top right of idle screen (#0, #1, etc.)
    - Pass rocket ID as runtime parameter to telemetry builder
    Gateway: Fix single-rocket display showing wrong ID
    - Was always showing "R0" when only one rocket active
    - Now correctly shows actual rocket ID (e.g. "R4")
    [firmware_gateway_heltec.ino, main.c, status_display.c]
2026-01-30 Gateway: Improve rocket GPS status display
    - Show satellite count (yellow) when rocket has GPS but gateway doesn't
    - Show satellite count (gray) when rocket is acquiring GPS
    - Show "noGPS" when no GPS data from rocket
    - Previously just showed "GPS..." which was unclear
    [firmware_gateway_heltec.ino]
2026-01-30 Flight: Fix rocket ID not persisting after restart
    Settings storage was using 0x7FE000 which conflicts with flight index.
    Moved settings to 0x7FD000 (third-to-last sector) to avoid collision.
    Flash layout now:
    - 0x780000-0x7CFFFF: Flight data slots
    - 0x7FD000: Device settings (rocket ID)
    - 0x7FE000: Flight index
    - 0x7FF000: Calibration
2026-01-31 Firmware: Add OTA updates, mDNS, auto-incrementing build numbers
    Heltec Gateway:
    - Add OTA (Over-The-Air) update support via ArduinoOTA
    - Add mDNS for network discovery (RocketGateway.local)
    - Advertise _rocket._tcp service with version/type TXT records
    - Fix GPS baud rate (115200 for UC6580 module)
    - Add GPS debug output and health monitoring
    - Add gps_chars, gps_passed, gps_failed to gw_info response
    All Firmware:
    - Replace version string with auto-incrementing build number
    - Add increment_build.cmake (CMake) and increment_build.sh (Arduino)
    - Version now displays as "Build N" with date/time
    - Build number persists in build_number.txt
    Flight Computer:
    - Add rocket name storage in flash (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
    [firmware_gateway_heltec.ino, main.c, status_display.c]
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2026-01-31 Gateway: Add GPS debugging commands and UC6580 configuration
    GPS improvements:
    - Configure UC6580 GNSS systems (GPS+BDS+GALILEO+SBAS+QZSS)
    - Enable GGA, RMC, GSV, GSA NMEA messages at 1Hz
    - Add gps_debug command for troubleshooting
    - Returns TinyGPS++ statistics, satellite info, HDOP, location age
    - Capture raw NMEA sentences for diagnosis
    - Increment build number to 17
    Note: Internal GPS antenna has weak reception. External active GPS
    antenna recommended for reliable satellite fixes.
    [firmware_gateway_heltec.ino]
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2026-02-02 Heltec Flight: Add ICM-20649 wide-range IMU support
    Added support for ICM-20649 IMU (±30g, ±4000dps) as preferred sensor:
    - Better for rockets: won't clip during high-g motor burns
    - Auto-detects ICM-20649 first, falls back to LSM6DSOX
    - ICM-20649 is also cheaper ($14.95 vs $19.95)
    - Add ICM-20649 register definitions and bank-switching
    - Add initICM20649() and readICM20649() functions
    - Update LSM6DSOX to use max range (±16g, ±2000dps)
    - Auto-detect IMU type at startup
    - Display detected IMU type and range in serial output
    - Update CLAUDE.md and parts list documentation
    IMU comparison:
    | IMU | Accel | Gyro | Price | Best For |
    |-----|-------|------|-------|----------|
    | ICM-2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
    [firmware_flight_heltec.ino]
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2026-02-03 Add BMP581 barometer support with auto-detection
    - Add BMP581 driver (initBMP581, readBMP581 functions)
    - Auto-detect barometer: try BMP581 first, fall back to BMP390
    - BMP581 offers 7.5x better accuracy (±3.3cm vs ±25cm), 240Hz, lower noise
    - Update parts list to recommend BMP581 ($9.95 vs $12.50)
    - Update documentation with sensor comparison tables
    - Total Heltec flight computer cost now ~$74 (41% savings vs RP2040)
    [firmware_flight_heltec.ino]
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2026-02-03 Add sensor type strings to RP2040 fc_info response
    Flight Computer (RP2040):
    - Add baro_type string ("BMP390" or "None") to device info packet
    - Add imu_type string ("LSM6DSOX+LIS3MDL" or "None") to device info packet
    Gateway (RP2040):
    - Fix fc_info parsing to match actual flight computer format
    - Parse rocket_id and rocket_name fields
    - Parse new baro_type and imu_type string fields
    - Include sensor types in JSON output when present
    This makes the RP2040 firmware compatible with the updated apps
    that now display specific sensor types in Device Info.
    [main.c]
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2026-02-04 Heltec Gateway: Add GPS antenna power and diagnostic commands
    - Enable active antenna power ($CFGANT,1) during GPS init
    - Add gps_cmd command to send arbitrary GPS commands for debugging
    - Helps diagnose GPS antenna issues on Heltec Wireless Tracker
    [firmware_gateway_heltec.ino]
2026-02-05 Add ICM-20649 IMU support and complementary filter for velocity fusion
    Add auto-detecting ICM-20649 wide-range 6-DoF IMU driver alongside
    existing LSM6DSOX, with MSB-first data handling and DLPF configuration.
    Implement 3-state complementary filter (altitude, velocity, accel bias)
    fusing IMU acceleration integration with barometric altitude correction.
    Falls back to barometric-only velocity when no IMU is connected.
    Prioritize BMP390 over BMP581 for barometric measurements due to
    BMP581's incorrect empirical conversion divisors.
    Also includes BMP581 driver fixes (chip ID, register bit layout,
    OSR/ODR configuration) and display updates for generic baro/IMU types.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
    [bmp581.c, imu.c, main.c]
2026-02-05 Fix BMP581 driver init, add dual-barometer comparison, update documentation
    BMP581 init was failing due to strict POR and NVM completion checks. Made
    both non-fatal with retry loops so the sensor initializes reliably. Verified
    Bosch-standard conversion divisors (/65536 temp, /64 pressure) produce
    correct values matching BMP390 within 8 Pa and 0.33°C.
    Added baro_compare debug command (0x0A) that streams dual-sensor comparison
    data through the gateway at 1 Hz, with diagnostic error reporting when a
    sensor fails to initialize. Gateway decodes comparison packets as JSON.
    New docs/SENSORS.md covers the full sensor fusion pipeline: barometric
    altitude formula, complementary filter with bias est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
    [bmp581.c, firmware_gateway_heltec.ino, main.c]
2026-02-05 Set ICM-20649 as primary IMU and BMP390 as primary barometer
    Swap IMU probe order to try ICM-20649 first (wider range, preferred for
    flight), falling back to LSM6DSOX. Update display and startup summary to
    show BMP390 as primary barometer when both sensors are present.
    [imu.c, main.c]
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2026-02-13 Add I2C bus safety, watchdog, display features, and printf suppression
    I2C Bus Safety:
    - Add TestI2CBus() — GPIO-level cable/bus test runs before i2c_init()
    to detect bad StemmaQT cables (stuck lines, SDA-SCL shorts)
    - Includes bus recovery (9 SCL clocks + STOP) for slave lockup after
    MCU reset mid-transaction
    - If test fails, I2C peripheral is NOT initialized — prevents system
    hang from bad cable. LoRa, display, GPS, flash continue working
    - Device info screen shows "I2C FAIL" when bus test fails
    Hardware Watchdog:
    - 8-second watchdog timer enabled before main loop
    - Fed every iteration — resets MCU if any subsystem hangs
    - On reboot, bus test catches the fault
    Display Improve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
    [bmp581.c, diskio.c, heartbeat_led.c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]
2026-02-13 Harden firmware reliability: eliminate infinite loops, check return values
    Fixes five reliability risks found by auditing the LoRa driver, heartbeat
    LED, main loop, and flash storage:
    1. SPI FIFO drain loops (lora_radio.c): Replace unbounded while loops with
    for loops limited to 16 iterations. The RP2040 SPI FIFO is only 8 deep,
    so 16 is generous. Prevents infinite loop if eInk bit-bang noise leaves
    the SPI peripheral stuck readable.
    2. IMU_Read return value (main.c): Check return before feeding data to the
    complementary filter. On I2C failure, skip the update to avoid stale
    data corrupting velocity/altitude calculations.
    3. Non-blocking PIO write (heartbeat_led.c): Replace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
    [heartbeat_led.c, lora_radio.c, main.c]
2026-02-13 Add Adafruit Ultimate GPS Breakout (5440) support and wiring diagram
    The existing NMEA parser already handles the MTK3333's $GN prefix
    (multi-GNSS) since it matches at offset +3 for GGA/RMC, so no parser
    changes were needed. The UART config is identical (9600 baud, 3.3V).
    - docs/GPS.md: Add supported modules comparison table (MT3339 vs MTK3333),
    wiring diagram for breakout-to-Feather connection (4 wires: VIN, GND,
    TX, RX), and notes on external antenna, EN/PPS pins, backup battery
    - docs/HARDWARE.md: Update BOM with GPS Breakout (PID 5440), fix GPS pin
    assignments (GP0/GP1 UART0, not GP4/GP5), update troubleshooting
    - pins.h: Update GPS section comments to list both supported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
    [gps.c, pins.h]
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2026-02-14 Harden GPS driver: RX pull-up, bounded reads, disable DMA, zero-init buffers
    - Add RX pull-up before uart_init to prevent floating line noise
    - Bound UART read loop to 64 bytes to prevent hang if peripheral is stuck
    - Use direct register read instead of uart_getc to avoid spin-wait
    - Disable UART DMA request signals to prevent rogue DMA
    - Remove unnecessary PMTK commands (GPS defaults to 1Hz GGA+RMC)
    - Zero-initialize lat/lon parse buffers
    - Update pins.h GPS comments for clarity
    [gps.c, pins.h]
2026-02-16 Add eInk board auto-detection, fix display scrambling, add hardware docs
    Auto-detect eInk Breakout Friend vs Feather Friend at runtime by probing
    both pin sets (CS/DC) and checking BUSY response. Fix display scrambling
    regression caused by DC pin initialized HIGH instead of LOW during reset.
    Fix FormatFloat rounding overflow, stabilize velocity/accel string width,
    sync sPrevBuffer after each partial refresh, and reduce full refresh
    interval to prevent ghosting. Add altitude diagnostics to USB console.
    Add Feather Friend board modification guide and hardware schematics.
    [Adafruit Feather RP2040 RFM.brd, Adafruit Feather RP2040 RFM.sch, Adafruit eInk Breakout Friend.brd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]
2026-02-17 Fix eInk display heat and artifacts, add BUSY fallback and mDNS resolution
    Firmware (eInk display):
    - Replace busy_wait_us_32 with sleep_ms in Core1 display loop and
    UC8151D WaitReady, reducing core1 CPU from 100% spin to low-power
    __wfe() idle — resolves board overheating
    - Increase partial refresh fixed delay from 500ms to 800ms, fixing
    occasional vertical-line artifacts when BUSY is not wired
    - Add BUSY wired/not-wired detection with automatic fallback to
    fixed timing delays when BUSY pin is unconnected
    - Skip InitializeButtons() in DISPLAY_EINK builds to prevent GP9
    pin conflict with eInk Feather Friend CS
    - Add mDNS resolution for .local hostnames in FlightConn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
    [main.c, uc8151d.c]
2026-02-24 Fix false flight detection, phantom button presses, and add GPS to Flight Complete
    Safety-critical fix: launch detection changed from OR to AND logic requiring
    altitude > 10m AND velocity > 10 m/s AND acceleration > 2g, with 5 consecutive
    samples. Barometric drift alone can no longer trigger false launches or fire
    ejection charges. Added 30-minute armed timeout auto-disarm and BOOST-to-COAST
    minimum velocity gate.
    Fixed phantom button presses in eInk builds: GP9/GP6/GP5 are eInk SPI chip
    selects, not buttons. Core1 toggling CS during SPI transfers caused
    ProcessButtons to cycle display mode to FlightStats (showing Flight Complete
    with all zeros). ProcessButtons now skipped in DISPLAY_EINK b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
    [main.c, pins.h, status_display.c]
2026-02-25 Require rocket ID for all commands, fix eInk display ARMED refresh, add LoRa retry
    Safety: All commands (arm, disarm, reset, download, orientation_mode) now require
    explicit rocket ID — no defaults. Gateway rejects commands without valid rocket ID.
    eInk fix: Always reinit UC8151D controller before full refresh to clear partial
    refresh state that prevented screen transitions (IDLE→ARMED showed stale content).
    Made sDisplayShared volatile for cross-core visibility between Core0 and Core1.
    Gateway: Added LoRa command retry (3 attempts with 50ms gaps) for half-duplex
    timing collisions. Added rocket state tracking for display redraw.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
    [firmware_gateway_heltec.ino, main.c]
2026-02-25 iOS app: feature parity with desktop, fix connection, add Connect button
    - Require rocket ID on all commands (arm, disarm, flash_list, etc.)
    - Fix ACK parsing to use "id"/"ok" fields (was "cmd"/"success")
    - Add missing telemetry fields (IMU, gyro, mag, attitude, pyro, pressure)
    - Add new commands: reset, orientation mode, set rocket name, device info
    - Add link status and flash header event handlers
    - Add Connect button to main screen with Connecting.../error feedback
    - Fix FlightConnection.Connect to create fresh socket on each attempt
    - Fix Disconnect to raise ConnectionChanged event
    - Default gateway to RocketGateway.local:5000
    - Auto-select rocket ID from first telemetry received
    Co-Aut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
2026-02-26 iOS app: Add native UIMenu, About/Rockets screens, side-by-side telemetry layout
    Replace pushed menu screen with native iOS pull-down UIMenu (via ObjC declares)
    accessible from all screens. Add About screen with app icon and Rockets screen
    for multi-rocket selection. Rearrange altitude/velocity displays side-by-side
    to free vertical space for the rocket list.
2026-02-26 Fix GPS satellite parsing, connect Recovery screen, add app icon, target iOS 26
    - Fix "sats" JSON field name mismatch in both iOS and desktop apps (was "sat")
    - Derive GPS fix from satellite count (gateway doesn't send fix field)
    - Add satellite info to TableRockets with in-place cell updates
    - Connect Recovery screen: initialize App.pRocketLocation, call
    UpdateFromTelemetry on each sample, add 1-sec refresh timer
    - Fix altitude/velocity scientific notation (use Str with format string)
    - Add app icon to project, update minimum iOS version to 26.0
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
